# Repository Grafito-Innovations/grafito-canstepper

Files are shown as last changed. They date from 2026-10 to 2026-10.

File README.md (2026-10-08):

# Grafito CANStepper

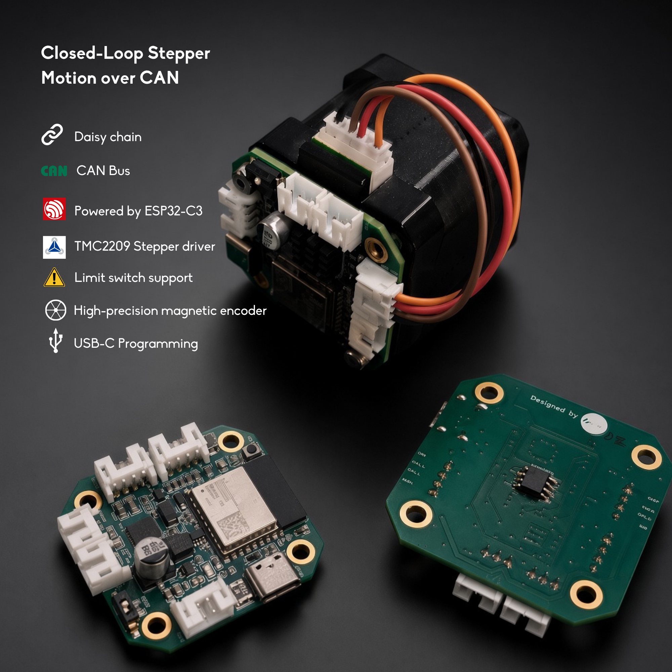
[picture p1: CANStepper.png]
Grafito CANStepper


Closed-loop stepper motor control over CAN. Each board carries an ESP32-C3,
a TMC2209 driver, an MT6701 14-bit magnetic encoder and a CAN transceiver;
up to 31 boards daisy-chain on one 1 Mbps bus and are driven from Python
through the USB port of any board on the chain.

```
├── canstepper/                              # Python package (grafito-canstepper)
├── firmware/GrafitoCANStepper_C3/           # node firmware (GCSP v1, fw 1.12)
├── firmware/GrafitoCANStepper_C3_CANopen/   # optional CiA 301/402 SKU (fw 2.1)
├── examples/                                # runnable examples + machine.toml
├── tests/                                   # pytest suite (runs on a software sim)
├── model_assets/                            # assembly render, PCB drawing, STEP CAD
└── docs/                                    # flashing, protocol, quickstart, CAD
```

## Product links

- **Shop / brochure:** [CANStepper Adapter Board](https://grafito.in/shop/products/canstepper-adapter-board/)
- **Amazon (India):** https://www.amazon.in/dp/B0H8XZ6V99
- **Docs:** https://docs.grafito.in
- **Board test station:** https://docs.grafito.in/dashboard
- **Mechanical CAD & drawings:** https://docs.grafito.in/docs/mechanical-cad
- **PyPI:** [grafito-canstepper](https://pypi.org/project/grafito-canstepper/)

CAD and brochure files in this repo (`model_assets/`):

| File | Description |
| --- | --- |
| `CANStepper.png` | Product photo (also at repo root) |
| `CANStepper_pinout.png` | Connector / pinout diagram |
| `CANStepper_multiaxis_can.png` | Multi-axis CAN bus demonstration |
| `CANStepper_V1_assembly.mp4` | V1 board assembly video (historical) |
| `CANStepper_V1_assembly_preview.jpg` | Preview frame for the V1 video |
| `CANStepper_test_station.png` | Board Test Station (after USB connect) |
| `CANStepper_block_diagram.png` | System block diagram |
| `CANStepper_V2_Assembly.webp` | V2 assembly render |
| `Drawing_CANStepper_V2.pdf` | V2 PCB mechanical drawing |
| `CANStepperV2_3D_PCB.step` | V2 PCB STEP |
| `CASING_MOUNT.step` | Casing / mount STEP |
| `Heat_Spreader.step` | Heat spreader STEP |
| `TMC2209 UART Stepper Driver - Heat_Sink.step` | TMC2209 heatsink STEP |
| `canstepper-brochure-v2.pdf` | Product brochure |

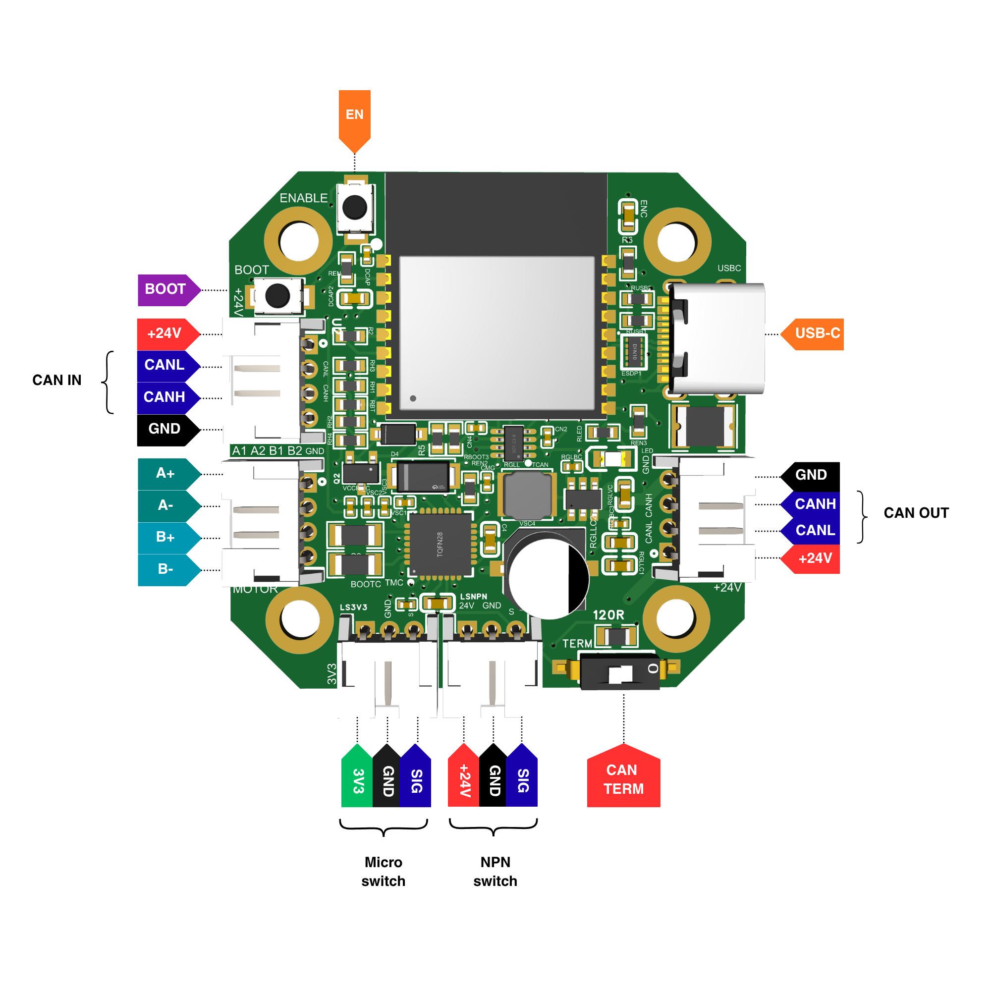
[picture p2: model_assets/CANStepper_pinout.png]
CANStepper pinout


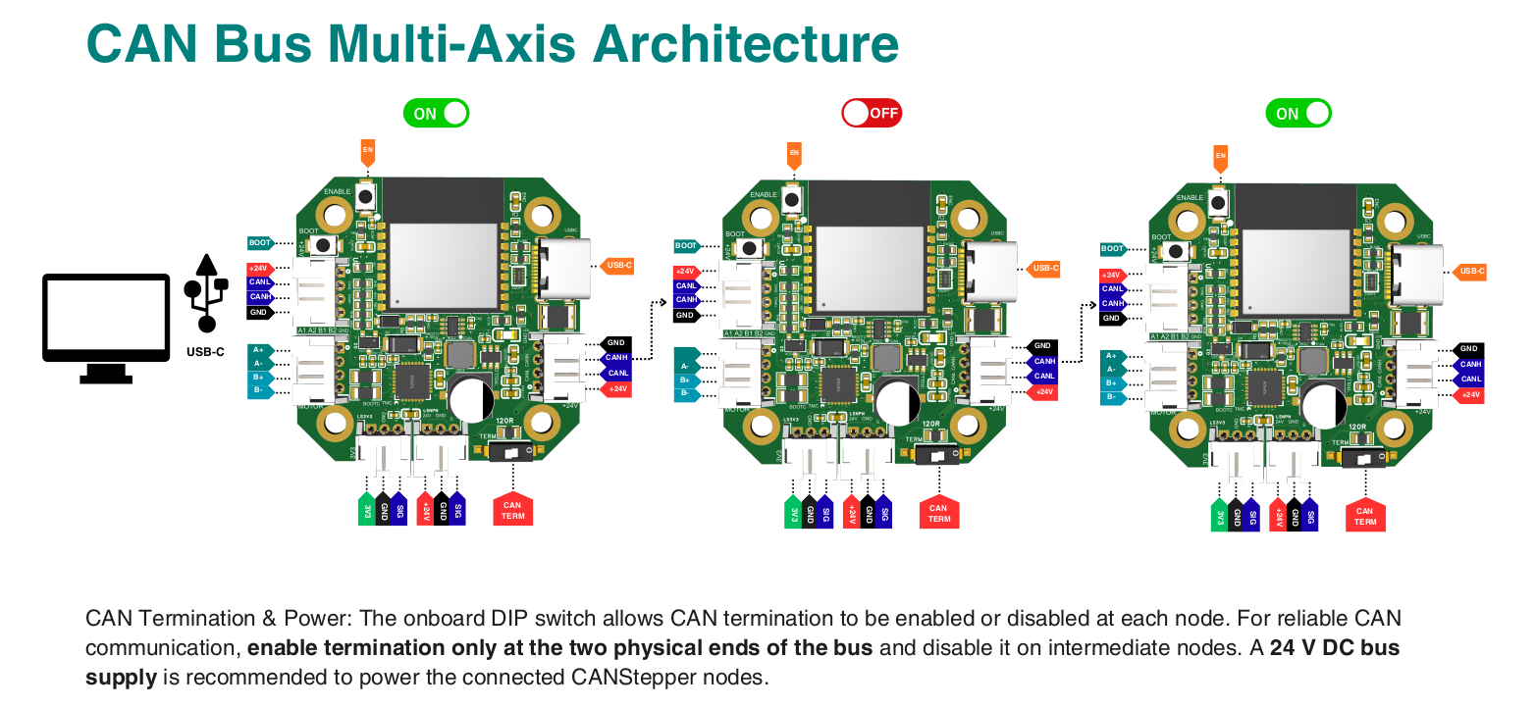
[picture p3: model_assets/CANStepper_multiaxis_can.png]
CAN bus multi-axis demonstration


**V1 board assembly** (click the preview to play the video):

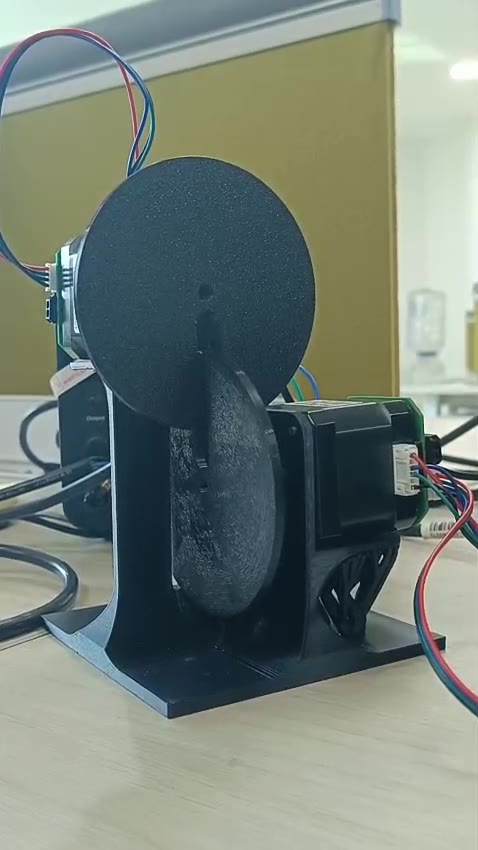
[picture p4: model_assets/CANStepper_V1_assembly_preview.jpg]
V1 board assembly


This clip is **version 1** of the same board. V1 used **three different
connector types**, which made cabling and crimping difficult. The current
production board is **V2**, with **JST 2.0** connectors throughout for easy
crimping.

> **Important — encoder magnet:** Fit a **diametrical** magnet on the motor
> shaft. The magnet polarity must be **radial**, not axial. An axial magnet
> will not produce a valid MT6701 angle and closed-loop control will fail.

After USB and Vin are connected, test the board in the
**[CANStepper Test Station](https://docs.grafito.in/dashboard)** — set the
node ID, enable the driver, jog, and check encoder / TMC / CAN telemetry.

<a href="https://docs.grafito.in/dashboard">
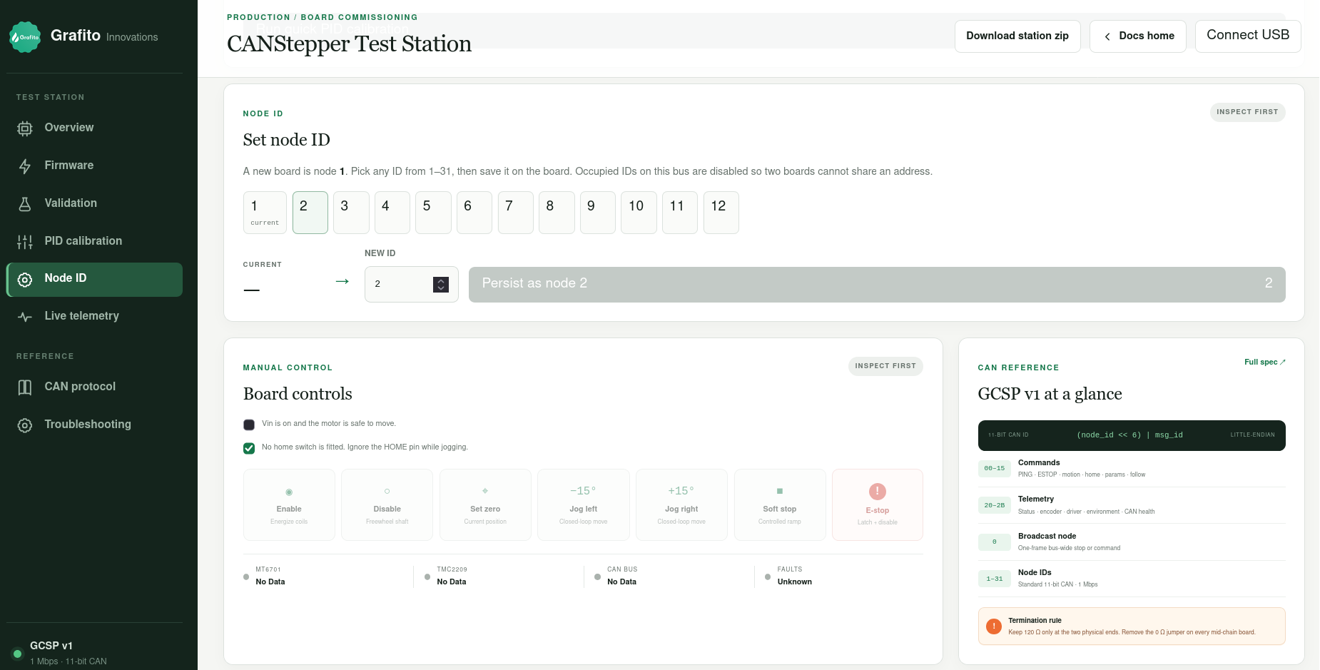
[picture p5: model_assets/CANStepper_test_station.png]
CANStepper Test Station
  
</a>

## Highlights

- **Layered Python API** — raw frames → `StepperNode` → `NodeGroup` →
  `Axis` (mm units via `rotation_distance`) → `DualMotorAxis` /
  `IndependentDualAxis` / `Cartesian` / `CoreXY` / `MotionGroup` →
  declarative `machine.toml`.
- **Safety scopes** — `node.estop()`, `group.estop()`, `bus.estop_all()`
  (single broadcast frame); e-stop is latched until re-enabled.
- **Homing** — physical endstop on IO8, sensorless (StallGuard), or
  set-zero; configurable current, backoff and timeout.
- **Closed loop** — firmware ≥1.12 plans a rest-to-rest **S-curve**
  trajectory with **velocity + acceleration feedforward** and a light
  tracking PID on the MT6701 encoder (optional encoder LUT). All motion
  limits are *configurable defaults*, never hard clamps.
- **On-bus leader/follower** — dual-motor gantries stay coupled with no
  host in the loop (`DualMotorAxis`).
- **Encoder-gated dual screws** — `IndependentDualAxis` commands both
  motors independently and **blocks the next pass until both encoders**
  are within mm tolerance of the target.
- **Simulator included** — `canstepper.sim.SimNetwork` implements the whole
  protocol in software; the test suite and the examples run without hardware.

## Install & first spin

```bash
pip install grafito-canstepper

# Development (from this directory):
# pip install -U pip setuptools && pip install -e ".[dev]"
```

```python
from canstepper import CANStepperBus

with CANStepperBus.serial("/dev/ttyACM0") as bus:
    print(bus.discover())
    node = bus.node(1)
    node.set_run_current(40).enable()
    node.move_to(360.0, blocking=True)
```

Continue with:

- [docs/flashing.md](docs/flashing.md) — Arduino IDE + arduino-cli (GCSP and CANopen)
- [docs/canopen.md](docs/canopen.md) — EDS/DCF, PLC enable, tune Kp/Ki/Kd/Ka
- [docs/quickstart.md](docs/quickstart.md) — first motion
- [docs/closed_loop_tuning.md](docs/closed_loop_tuning.md) — trapezoid + v_ff
- [docs/protocol.md](docs/protocol.md) — GCSP v1 wire protocol
- [docs/mechanical_cad.md](docs/mechanical_cad.md) — CAD, drawings, assembly video

G-code examples (from this directory):

```bash
PYTHONPATH=. python3 examples/gcode_cartesian.py /dev/ttyACM0 1 2
PYTHONPATH=. python3 examples/gcode_corexy.py /dev/ttyACM0 1 2
PYTHONPATH=. python3 examples/gcode_from_file.py examples/gcode/square.gcode
```

Homing examples (IO8 endstop, StallGuard sensorless, set-zero):

```bash
PYTHONPATH=. python3 examples/home_endstop.py /dev/ttyACM0 1 -1
PYTHONPATH=. python3 examples/home_sensorless.py /dev/ttyACM0 1 -1 60
PYTHONPATH=. python3 examples/home_set_zero.py /dev/ttyACM0 1
```

Belt axis (mm):

```bash
PYTHONPATH=. python3 examples/belt_move_mm.py /dev/ttyACM0 1 50 77.2 150
```

## Development

```bash
python3 -m pytest
```

Current GCSP firmware is **1.12** (S-curve + Ka + LUT; motors off at boot
until `enable()`). Optional **CANopen 2.1** lives in
`firmware/GrafitoCANStepper_C3_CANopen/` with `GrafitoCANStepper.eds` and
`GrafitoCANStepper_Node1.dcf` / `GrafitoCANStepper_Node2.dcf`
(FileRevision 2, identity `0x00020100`). Discard any older 2.0 EDS — it
will not import this board. Node 2 must be flashed with
`-DCO_FACTORY_NODE_ID=2`. See [docs/canopen.md](docs/canopen.md) and
**https://docs.grafito.in/docs/canopen**. PLC gains: 0x200F Kp, 0x2010 Ki,
0x2011 Kd, 0x201A Ka (REAL32). Do not mix GCSP and CANopen on one bus.

**How to flash (Arduino IDE + arduino-cli, GCSP and CANopen):**
[docs/flashing.md](docs/flashing.md) · https://docs.grafito.in/docs/flashing

Firmware builds with Arduino IDE or `arduino-cli` (ESP32C3 Dev Module, USB
CDC On Boot = Enabled; libraries: FastAccelStepper, TMC2209 janelia-arduino).
**Apply Vin (5–24 V, typically 24 V) before upload** — USB-C is data only and
does not power the ESP32 for programming. CAN termination is **on by default**
(0 Ω jumper); remove that 0 Ω on mid-chain daisy-chain nodes.

```bash
arduino-cli compile --fqbn esp32:esp32:esp32c3:CDCOnBoot=cdc \
  firmware/GrafitoCANStepper_C3
arduino-cli upload -p /dev/ttyACM0 --fqbn esp32:esp32:esp32c3:CDCOnBoot=cdc \
  firmware/GrafitoCANStepper_C3
```

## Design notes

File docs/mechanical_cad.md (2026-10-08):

# Mechanical CAD & drawings

Published with in-page previews at **https://docs.grafito.in/docs/mechanical-cad**.

Source files live in `model_assets/` at the repo root. These are the **V2**
board assets used on the shop and docs sites.

| File (repo) | Published path | Description |
| --- | --- | --- |
| `CANStepper.png` | `/model-assets/canstepper.png` | Product photo |
| `CANStepper_pinout.png` | `/model-assets/canstepper-pinout.png` | Connector / pinout diagram |
| `CANStepper_multiaxis_can.png` | `/model-assets/canstepper-multiaxis-can.png` | Multi-axis CAN bus demonstration |
| `CANStepper_V1_assembly.mp4` | — | V1 board assembly video (historical) |
| `CANStepper_block_diagram.png` | `/model-assets/canstepper-block-diagram.webp` | System block diagram |
| `CANStepper_V2_Assembly.webp` | `/model-assets/canstepper-v2-assembly.webp` | V2 assembly render |
| `Drawing_CANStepper_V2.pdf` | `/model-assets/canstepper-v2-drawing.pdf` | V2 PCB mechanical drawing |
| `CANStepperV2_3D_PCB.step` | `/model-assets/canstepper-v2-3d-pcb.step` | V2 PCB STEP (~24 MB) |
| `CASING_MOUNT.step` | `/model-assets/canstepper-casing-mount.step` | Casing / mount STEP |
| `Heat_Spreader.step` | `/model-assets/canstepper-heat-spreader.step` | Heat spreader STEP |
| `TMC2209 UART Stepper Driver - Heat_Sink.step` | `/model-assets/tmc2209-heat-sink.step` | TMC2209 heatsink STEP |
| `canstepper-brochure-v2.pdf` | `/brochures/canstepper-brochure-v2.pdf` | Product brochure |

Shop product page CAD section:
https://grafito.in/shop/products/canstepper-adapter-board/#mechanical-cad

Brochure:
https://grafito.in/brochures/canstepper-brochure-v2.pdf

## Videos

| Topic | URL | Docs embed |
| --- | --- | --- |
| V1 assembly (this repo) | [model_assets/CANStepper_V1_assembly.mp4](../model_assets/CANStepper_V1_assembly.mp4) | Historical V1 board — mixed connectors |
| Assembly walkthrough | https://www.youtube.com/watch?v=ULpthBzb50s | https://docs.grafito.in/docs/mechanical-cad#assembly-video |
| Leader / follower (encoder mirror) | https://www.youtube.com/shorts/0dZ-bfxO9gM | https://docs.grafito.in/docs/motion#dual-motor-axes-eg-dual-z-gantries |

The V1 clip shows an earlier revision of the same board. V1 used **three
different connector types**, which made cabling and crimping difficult. The
current production board is **V2**, with **JST 2.0** connectors throughout.

> **Important — encoder magnet:** Use a **diametrical** magnet on the motor
> shaft. Polarity must be **radial**, not axial. An axial magnet will not
> give a valid MT6701 reading.

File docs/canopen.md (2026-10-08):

# CANopen / CiA 402 (PLC)

Optional firmware **2.1** for a PLC that imports an EDS. Production Python
machines still use **GCSP 1.12**. **Do not mix GCSP and CANopen on the same
CAN bus.**

- Firmware + EDS/DCF: `firmware/GrafitoCANStepper_C3_CANopen/`
- Flash (including factory node 2): [flashing.md](flashing.md)
- Human docs: https://docs.grafito.in/docs/canopen

Import **firmware 2.1** `GrafitoCANStepper.eds` (FileRevision 2, identity
`0x00020100`). Delete any older 2.0 EDS. For node 2 import
`GrafitoCANStepper_Node2.dcf` and flash with `-DCO_FACTORY_NODE_ID=2`.

Enable: controlword `0x6040` = `6 → 7 → 15`. Units are encoder counts
(16384 / rev).

## Tune gains from the PLC

Closed-loop command is:

```
v = v_ff + Ka · a_ff + PID(r − encoder)
```

PID only **trims lag**. Cruise speed is **not** a PID gain — set that with
`0x6081`. Write the gain objects as **REAL32** (IEEE-754). In TwinCAT /
Codesys map them as **REAL**. Do not write integer `10` into `0x200F`; it
must be float `10.0`.

### Objects to change

| Index | Name | Type | Factory | What it does |
| --- | --- | --- | --- | --- |
| **0x200F** | Kp | REAL32 | **10.0** | Stiffness. Raise if it lags the plan; lower if it buzzes. |
| **0x2011** | Kd | REAL32 | **0.35** | Damping. Raise if it rings at the end of a move. |
| **0x2010** | Ki | REAL32 | **0.3** | Steady-state. Keep small; too much causes overshoot / following error `0x7122`. |
| **0x201A** | Ka | REAL32 | **0.04** | Accel feedforward. Raise if it sags during accel/decel. |
| **0x2012** | PID tolerance | REAL32 | **0.35°** | Target-reached band. Too tight at high RPM → `0x7122`. |

### Set these before touching PID

| Index | Name | Notes |
| --- | --- | --- |
| **0x2006** | Invert | `1` if a positive target runs the wrong way (PID will fight the encoder). |
| **0x2003** | Run current % | Start **30–40**. Gains cannot fix a starved motor. |
| **0x2007** | Closed loop | Must be **1** for encoder PID (`0` = open-loop step pulses). |
| **0x6081** | Profile velocity | counts/s. Default `32768` ≈ 720 °/s. |
| **0x6083** | Profile accel | counts/s². Default `65536` ≈ 1440 °/s². |
| **0x201B** | Jerk | deg/s³. **0 = auto** (amax / 0.05 s). |

Save so it survives power-cycle: write **0x2008 = 1**.

### Order on the PLC

1. Enable `6 → 7 → 15`, confirm `0x2007 = 1`, invert with `0x2006` if needed.
2. Set a modest `0x6081` / `0x6083` and current **30–40**.
3. Leave **Ki = 0.3** and **Ka = 0.04**.
4. Change **Kp** in steps of ~2 (try 8 → 10 → 12).
5. If it oscillates at settle, raise **Kd** (0.35 → 0.5) or drop Kp.
6. Only then nudge **Ka** or **Ki**.
7. Write `0x2008 = 1` when it is good.

Measured precision defaults (fw 2.1 / GCSP 1.12): Kp **10**, Ki **0.3**,
Kd **0.35**, Ka **0.04**, tolerance **0.35°**.

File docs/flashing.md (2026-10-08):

# Flashing firmware

Step-by-step upload for a Grafito CANStepper board (ESP32-C3). Pick **one**
sketch per board. **Do not mix GCSP and CANopen on the same CAN bus** — the
ID maps collide.

| Sketch | Version | When to use |
| --- | --- | --- |
| `firmware/GrafitoCANStepper_C3` | **GCSP 1.12** | Python (`grafito-canstepper`), G-code, Test Station |
| `firmware/GrafitoCANStepper_C3_CANopen` | **CANopen 2.1** | PLC that imports an EDS / DCF |
| `firmware/CANStepper_WiFiPortal` | demo | Phone browser bench UI only |

Public docs: **https://docs.grafito.in/docs/flashing**  
Firmware downloads: **https://docs.grafito.in/docs/firmware**  
Source: **https://github.com/Grafito-Innovations/grafito-canstepper**

## 1. Power and USB (do this first)

USB-C on this board is **data only**. It does **not** power the ESP32 for
programming.

1. Apply **Vin 5–24 V** (typically **24 V**) to the power / CAN connector.
2. Then plug USB-C into the host.
3. Keep Vin connected for the whole compile + upload. If Vin drops, the port
   disappears and the flash fails.

Do **not** hold a HOME switch closed at power-on. GPIO8 is a strapping pin:
if it is held LOW at reset, the C3 can enter download boot and look “dead”.
Leave HOME open (pin HIGH) until the board has booted.

## 2. Host tools (once per computer)

### Option A — Arduino IDE 2 (GUI)

1. Install [Arduino IDE 2](https://www.arduino.cc/en/software).
2. **File → Preferences → Additional boards manager URLs**, add:

   ```
   https://espressif.github.io/arduino-esp32/package_esp32_index.json
   ```

3. **Boards Manager:** install **esp32** by Espressif Systems.
4. **Library Manager:** install
   - **FastAccelStepper** (gin66)
   - **TMC2209** (janelia-arduino / Peter Polidoro)

### Option B — arduino-cli

```bash
curl -fsSL https://raw.githubusercontent.com/arduino/arduino-cli/master/install.sh | sh
export PATH="$HOME/bin:$PATH"

arduino-cli config init
arduino-cli config add board_manager.additional_urls \
  https://espressif.github.io/arduino-esp32/package_esp32_index.json
arduino-cli core update-index
arduino-cli core install esp32:esp32
arduino-cli lib install FastAccelStepper
arduino-cli lib install TMC2209
```

On Debian/Ubuntu, add your user to `dialout` (log out and back in once):

```bash
sudo usermod -aG dialout "$USER"
```

## 3. Board settings (both IDE and CLI)

| Setting | Value |
| --- | --- |
| Board | **ESP32C3 Dev Module** |
| USB CDC On Boot | **Enabled** |
| Upload Speed | 921600 (drop to 115200 if uploads flake) |
| Flash Size | 4 MB (default) |
| Port | Linux `/dev/ttyACM0`, macOS `/dev/cu.usbmodem*`, Windows `COMx` |

**Arduino IDE:** **Tools → Board → esp32 → ESP32C3 Dev Module**, then
**Tools → USB CDC On Boot → Enabled**, then **Tools → Port**.

**FQBN** used by `arduino-cli`:

```
esp32:esp32:esp32c3:CDCOnBoot=cdc
```

Find the port after Vin + USB are connected:

```bash
# Linux
ls /dev/ttyACM* /dev/ttyUSB*

# macOS
ls /dev/cu.usbmodem*

# Windows (PowerShell)
Get-CimInstance Win32_SerialPort | Select-Object DeviceID, Name
```

If two ACM devices appear, pick the CDC serial port (the one that shows the
boot banner at 115200). Opening that port **resets** the ESP32-C3 — wait for
the banner before talking to the board.

## 4. Flash GCSP 1.12 (Python / Test Station)

Arduino requires the folder name to match the `.ino` name. In this repo that
is already `firmware/GrafitoCANStepper_C3/GrafitoCANStepper_C3.ino`.

### Arduino IDE

1. **File → Open** `firmware/GrafitoCANStepper_C3/GrafitoCANStepper_C3.ino`.
2. Confirm board / CDC / port from the table above.
3. Click **Upload**. Wait until you see “Hard resetting via RTS pin…”.
4. **Tools → Serial Monitor**, 115200 baud.

### arduino-cli

From the repository root:

```bash
arduino-cli compile --fqbn esp32:esp32:esp32c3:CDCOnBoot=cdc \
  firmware/GrafitoCANStepper_C3
arduino-cli compile --upload -p /dev/ttyACM0 \
  --fqbn esp32:esp32:esp32c3:CDCOnBoot=cdc \
  firmware/GrafitoCANStepper_C3
```

Windows: replace `-p /dev/ttyACM0` with `-p COM5` (your port).

### Healthy GCSP banner

```
# GrafitoCANStepper fw 1.12 proto 1
# HOME pin GPIO8 INPUT_PULLUP raw=HIGH (strapping: keep HIGH at power-on)
# HOME: INPUT_PULLUP + endstop enable=1 active_high=1 action=stop (fw 1.12)
# POWER: enable_on_boot=0 hold<=5 run<=40 standstill=freewheel (fw 1.9)
# MT6701 SSI mode=3 encoder-loss-filter=25ms
# CAN started (1 Mbps)
```

Motors stay **off** until the host calls `enable()` (fw ≥1.9). Continue with
[quickstart.md](quickstart.md) or the
[Test Station](https://docs.grafito.in/dashboard).

GCSP node ID is stored in NVS and **survives a reflash**. Default is **1**.
Change it from Python (`node.set_node_id(n)` then `save_config()`), then
power-cycle. Do this **before** putting two boards on one CAN bus.

## 5. Flash CANopen 2.1 (PLC)

Flash the **folder**, not a lone `.ino`. The sketch includes `canopen_stack.h`.

```
firmware/GrafitoCANStepper_C3_CANopen/
  GrafitoCANStepper_C3_CANopen.ino
  canopen_stack.h
  GrafitoCANStepper.eds
  GrafitoCANStepper_Node1.dcf
  GrafitoCANStepper_Node2.dcf
```

Same board settings as GCSP (ESP32C3 Dev Module, USB CDC On Boot Enabled,
FastAccelStepper + TMC2209).

### Factory node 1 (default)

```bash
arduino-cli compile --upload -p /dev/ttyACM0 \
  --fqbn esp32:esp32:esp32c3:CDCOnBoot=cdc \
  firmware/GrafitoCANStepper_C3_CANopen
```

Heartbeat COB-ID is `0x701`. Import `GrafitoCANStepper.eds`, then
`GrafitoCANStepper_Node1.dcf` if the PLC wants a commissioned instance.

### Factory node 2 (customer PLC pack)

If the PLC imports **`GrafitoCANStepper_Node2.dcf`**, the board **must** be
node 2. Heartbeat `0x702`, SDO `0x602` / `0x582`, RPDO1 `0x202`, TPDO1 `0x182`.

**arduino-cli:**

```bash
arduino-cli compile --upload -p /dev/ttyACM0 \
  --fqbn esp32:esp32:esp32c3:CDCOnBoot=cdc \
  --build-property "compiler.cpp.extra_flags=-DCO_FACTORY_NODE_ID=2" \
  firmware/GrafitoCANStepper_C3_CANopen
```

**Arduino IDE:** at the **top** of `GrafitoCANStepper_C3_CANopen.ino` (before
the `#ifndef CO_FACTORY_NODE_ID` block), add:

```cpp
#define CO_FACTORY_NODE_ID 2
```

Then Upload. Revert that line before flashing a node-1 board.

### Healthy CANopen banner (node 2)

```
# GrafitoCANStepper CANopen fw 2.1 CiA402
702 0 00
# CAN started (1000000 bit/s) node 2
702 0 7F
```

Opening the USB serial monitor **resets** the C3. Wait for `7F` (pre-operational
heartbeat) before the PLC starts SDOs.

CANopen NVS namespace is `co402`. It does **not** inherit a GCSP node ID.
After a first flash, if NVS already stored a different ID, write object
`0x2000` = desired ID, `0x2008` = 1 (save), then reset.

PLC import: delete any older **2.0** EDS (revision `0x00020000`), then import
the **2.1** `GrafitoCANStepper.eds` (FileRevision 2, revision `0x00020100`)
and the matching Node DCF.

## 6. Confirm the flash

| You flashed | Serial (115200) | Host check |
| --- | --- | --- |
| GCSP 1.12 | `fw 1.12 proto 1` | `pip install -U grafito-canstepper` then `bus.discover()` → `{1: '1.12'}` |
| CANopen 2.1 node 1 | `CANopen fw 2.1` and `node 1` | Heartbeat `701 0 7F`. Python `discover()` is **empty** (wrong protocol) |
| CANopen 2.1 node 2 | `node 2` | Heartbeat `702 0 7F` |

Empty `discover()` after a CANopen flash is expected. Re-flash GCSP if you
need Python again.

## 7. If upload fails

| Symptom | Fix |
| --- | --- |
| Port missing / board not found | Vin first, then USB. Close Serial Monitor, Test Station, and other scripts. |
| `Failed to connect to ESP32: No serial data` | CDC On Boot was **Disabled** on the last flash, or GPIO8 held LOW at reset. Release HOME, hold **BOOT**, tap **RESET**, retry upload, then release BOOT. |
| Upload starts then stalls | Drop upload speed to 115200. Use a short USB data cable (not charge-only). |
| Linux `Permission denied` | `sudo usermod -aG dialout $USER` and re-login. |
| Banner is CANopen but you wanted Python | You flashed the PLC sketch. Flash `GrafitoCANStepper_C3`. |
| Two boards, CAN silent / collisions | Both still node 1. Set unique IDs **before** joining the bus. |
| PLC talks, motor never enables | Enable `6 → 7 → 15`. If HOME is already active, set `0x200C = 0`. |

## Related

- [Firmware downloads](https://docs.grafito.in/docs/firmware)
- [CANopen / CiA 402](canopen.md) — EDS, DCF, [tune gains from the PLC](canopen.md#tune-gains-from-the-plc)
- [Quickstart](quickstart.md)
- [Hardware (docs site)](https://docs.grafito.in/docs/hardware)

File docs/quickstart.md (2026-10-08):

# Quickstart — Grafito CANStepper (GCSP v1)

## 1. Hardware + firmware

Board: **[CANStepper Adapter Board](https://grafito.in/shop/products/canstepper-adapter-board/)** on the Grafito shop.
The current production board is **V2** (JST 2.0 connectors). Earlier **V1**
boards used three different connector types and are harder to cable.

> **Important — encoder magnet:** Mount a **diametrical** magnet on the shaft
> over the MT6701 (≈1–2 mm air gap). Magnet polarity must be **radial**, not
> axial. An axial magnet will not produce a valid encoder angle.

1. Apply main Vin (**5–24 V**, typically **24 V**). **USB does not power the
   ESP32 for programming** — Vin is required to flash; USB-C is data only.
2. Flash `firmware/GrafitoCANStepper_C3` (ESP32-C3, **USB CDC On Boot: Enabled**)
   with Vin connected. Full procedure: [flashing.md](flashing.md).
3. Open a serial monitor once: you should see a boot banner like  
   `# GrafitoCANStepper fw 1.12 proto 1` and an MT6701 self-check line with a
   live angle.
4. CAN: termination is **enabled by default** (0 Ω jumper → 120 Ω path). For
   daisy-chain mid-nodes, **remove the 0 Ω resistor**; keep termination on the
   two physical ends (pads can be shorted to restore end termination).
5. With USB and Vin connected, open the
   **[CANStepper Test Station](https://docs.grafito.in/dashboard)** to set the
   node ID, enable the driver, jog, and confirm encoder / TMC / CAN telemetry.

   <a href="https://docs.grafito.in/dashboard">
     CANStepper Test Station
   </a>
6. Install the host library (PyPI: `grafito-canstepper`, import `canstepper`):

```bash
pip install grafito-canstepper

# Development (editable, from this directory):
# pip install -U pip setuptools && pip install -e ".[dev]"
```

## 2. Talk to a node

```python
from canstepper import CANStepperBus

bus = CANStepperBus.serial("/dev/ttyACM0")
print(bus.discover())                        # {1: '1.12'}
node = bus.node(1)
node.enable()
print(node.get_position())                   # encoder degrees
```

## 3. Open-loop spin

```python
node.set_closed_loop(False)
node.set_run_current(40).set_microsteps(16)
node.run(360.0)          # deg/s continuous
# …
node.stop()
```

Open-loop **position** moves use FastAccelStepper’s own trapezoid
(accel → cruise → decel).

## 4. Direction polarity (important for closed loop)

Positive commands must make the encoder angle **increase**. If closed loop
runs away or faults with `NO_PROGRESS`, invert once and persist:

```python
node.set_direction(inverted=True)
node.save_config()
```

## 5. Closed-loop position moves (firmware ≥1.2)

Firmware **1.2+** plans a rest-to-rest **trapezoidal trajectory** for every
`MOVE_ABS` / `MOVE_REL` in closed loop:

```
v_ff(t)  = trapezoid(vmax=cl_max_speed, amax=cl_max_accel)
r(t)     = ∫ v_ff
v_cmd    = v_ff + Kp·(r − encoder) + Ki·∫ − Kd·v_meas
```

Same style of trap generator as [Klipper kinematics](https://www.klipper3d.org/Kinematics.html),
plus encoder tracking so the shaft lands on target. **Not S-curve** (no jerk
limit yet). Full theory, parameter matrix, and production numbers:
**[docs/closed_loop_tuning.md](closed_loop_tuning.md)**.

### Recommended production tune

Characterized on **PR42HS40-1204AF-02** (NEMA 17, 1.8°, 1.2 A, 3.2 mH,
4.2 kg·cm, D-shaft) at **24 V**, firmware **1.2**. Full matrix + **10 min
soak (478/478 settles, 100% success)** in
**[docs/closed_loop_tuning.md](closed_loop_tuning.md)**.

| Setting | Value | Why |
|---|---|-----|
| `cl_max_speed` | **4800 deg/s** (800 RPM) | Production cruise; soak-proven |
| Max proven | 6000 deg/s (1000 RPM) | OK at 70% (and short 100% bursts) |
| OL ceiling | ~7200 deg/s (1200 RPM) | Continuous `run()` tracking |
| `run_current` | **70%** | Continuous duty; 100% OK for short bursts only |
| `microsteps` | **8** | Best consistency vs 4 / 16 |
| `stealthchop` | **False** (SpreadCycle) | StealthChop sags at speed |
| Tracking PID | kp=12, ki=0.3, kd=0.10, tol=0.35° | Trim around v_ff only |

```python
node.configure_closed_loop_speed(
    4800.0,                 # cruise deg/s (÷6 = RPM)
    run_current=70,
    microsteps=8,
    stealthchop=False,      # SpreadCycle — required at high speed
    persist=True,
)
node.enable()
node.set_zero()
node.move_to(720.0, blocking=True)
```

### Quick matrix highlights (PR42HS40-1204AF-02, fw 1.12, 8 µstep, SpreadCycle)

| Current | Settles 720…6000? | Notes |
|---|---|---|
| 40–85% | Yes | Prefer **70%** continuous |
| 100% (with cool-down) | Yes in dedicated retest | USB drop risk if hammered hard |
| Open-loop `run()` @ 70–100% | Tracks to **~7200** deg/s | Continuous spin, no settle |
| Closed-loop position @ 70% | Cruise **4800–6000** | 10 min soak: **100% success** |

### Why closed-loop can look slower than open-loop `run()`

| Mode | Profile | Settles? |
|---|---|---|
| Open-loop `run()` | Constant speed | No |
| Open-loop `move_to` | Trapezoid (FAS) | Step count only |
| CL pre-1.1 | Pure PID chase | Overshoots at high vmax |
| CL 1.1 | Braking-capped PID | No planned cruise |
| CL 1.2 | Trap + v_ff + PID | Planned cruise + stop |
| **CL ≥1.12** | **S-curve + Ka + PID** | **Planned cruise + stop** |

Open-loop velocity never decelerates to a target. Closed-loop must. On long
moves, 1.12 reaches cruise if the distance is long enough — expected.

### Measure your motor

```bash
python3 tools/cl_speed_validate.py /dev/ttyACM0 1 70 8
python3 tools/cl_matrix.py /dev/ttyACM0 1 --quick
python3 examples/closed_loop_speed.py /dev/ttyACM0 1 4800
python3 examples/high_speed_test.py /dev/ttyACM0 1 70
```

## 6. Axis units (mm)

```python
from canstepper import Axis

axis = Axis(node, rotation_distance=8.0, name="z")  # 8 mm / rev leadscrew
axis.move_to(50.0, blocking=True)                   # mm
```

## 7. Homing

```python
# Endstop on IO8 (must be HIGH at boot — strapping pin):
node.configure_endstop(enabled=True, active_high=False, action="stop")
axis.home(method="endstop", direction=-1, speed=8.0, backoff=1.0)

# No switch? Sensorless (StallGuard) against a hard stop:
node.set_stall_threshold(60)
axis.home(method="stallguard", direction=-1, speed=5.0, current_percent=25)
```

## 8. Multi-axis time-sync

Host-side `MotionGroup` also uses trapezoid duration math so several axes
finish together (point-to-point, not continuous contouring / look-ahead):

```python
from canstepper import MotionGroup

g = MotionGroup([axis_x, axis_y])
g.move_to({"x": 10.0, "y": 20.0}, blocking=True)
```

## 9. Emergency stop

```python
node.estop()                 # one node (latched; enable() to recover)
bus.group([2, 3]).estop()    # a set of nodes
bus.estop_all()              # every node, single broadcast frame
```

## 10. Whole machines from a config file

See `examples/machine.toml`, then:

```python
from canstepper import Machine

with Machine.from_config("machine.toml") as m:
    m.home("z")
    m.axes["z"].move_to(50.0, blocking=True)
```

## Troubleshooting

| Symptom | Check |
|---|---|
| Flash fails / no CDC | **Vin (5–24 V) applied?** USB does not power ESP32 for programming |
| `discover()` is empty | Vin + USB; port name; USB CDC On Boot; `#` boot lines visible? |
| Motor silent, no hold | `node.enable()`; `run_current`; Vin present (typically 24 V) |
| Stalls / won't settle in closed loop | Raise `cl_max_speed`/`cl_max_accel`; SpreadCycle + higher current; fewer µsteps; `configure_closed_loop_speed()` |
| Closed loop slower than open-loop `run()` | Expected for short moves (accel+decel+settle); on long moves use fw ≥1.2 and raise cruise to the OL ceiling |
| Angle noisy / jumps while stationary | MT6701 SSI `SPI_MODE3`; magnet centering/gap; CLK/DO/CS wiring |
| Closed loop runs away / `NO_PROGRESS` | Toggle `node.set_direction(True)` so +command increases encoder |
| Encoder fault code 1 | Sustained SSI loss; reflash latest firmware (rides through isolated CRC errors) |
| Two-node bus dead | Default term ON — ends keep 0 Ω / pads shorted; mid-chain **remove 0 Ω**; `get_can_health()` |
| Board won't boot with endstop wired | IO8 HIGH at reset (strapping pin) |

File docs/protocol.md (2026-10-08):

# Grafito CAN Stepper Protocol v1 (GCSP v1)

Wire protocol between a host and Grafito CANStepper boards. This document is
sufficient to implement an independent host client. The Python reference
implementation is `canstepper/protocol.py`; the firmware is
`firmware/GrafitoCANStepper_C3/`.

## Physical layer

- CAN 2.0A, **standard 11-bit identifiers**, **1 Mbps**, TCAN3413 transceiver.
- Daisy-chained nodes; up to **31 nodes** per bus.
- On-board **120 Ω termination is enabled by default** via a **0 Ω jumper**.
  Keep termination only on the **two physical ends** of the bus; **remove the
  0 Ω resistor** on intermediate (mid-chain) boards. End boards can short the
  termination pads if the jumper was removed and end termination is needed again.

## Addressing

```
CAN ID (11 bit) = (node_id << 6) | msg_id
```

| Field | Bits | Range | Meaning |
|---|---|---|---|
| `node_id` | 10..6 | 0–31 | 0 = broadcast (every node executes), 1–31 = one board |
| `msg_id` | 5..0 | 0–63 | 0–31 command (host→node), 32–63 telemetry (node→host) |

- All multi-byte payload values are **little-endian**.
- A **remote frame (RTR)** carrying a telemetry `msg_id` requests that node to
  transmit the telemetry immediately (poll). Data frames with telemetry IDs
  are never executed as commands.
- Nodes also broadcast telemetry periodically: the *fast* group
  (POSITION, MOTION, PID_STATUS) at `fast_rate_hz` (default 10 Hz) and the
  *slow* group (STATUS, DRIVER, ENV, FOLLOW_STATUS, CAN_HEALTH) at
  `slow_rate_hz` (default 1 Hz). Either rate can be 0 (off).

## Serial bridge

Any node bridges its USB CDC port (115200 baud) to the bus. One text line per
frame, in both directions:

```
<CAN_ID hex> <RTR 0|1> <payload hex>\n
```

Example — command node 1 to 180°: `44 0 0000000000C06640`
(`0x44 = (1<<6)|4`, MOVE_ABS, f64 little-endian 180.0).

- Payload length = hex-digit count / 2 (0–8 bytes). RTR lines carry no payload.
- Lines beginning with `#` are human-readable debug output — ignore them.
- The bridging node executes bridged frames addressed to it (or broadcast)
  *and* re-transmits them on CAN; every frame it sees on the bus, plus its own
  telemetry, is printed to the port.

## Commands (msg_id 0–31)

| # | Name | Payload | Behavior |
|---|---|---|---|
| 0 | `PING` | — | Node answers with STATUS immediately. |
| 1 | `ESTOP` | — | Instant stop + driver hardware-disable. **Latched**: motion commands are ignored until `ENABLE 1`. |
| 2 | `STOP` | — | Decelerating stop; driver stays energized; cancels homing/velocity/position. |
| 3 | `ENABLE` | `u8` 0/1 | Driver off/on. Enabling clears the e-stop latch. Disabling force-stops. |
| 4 | `MOVE_ABS` | `f64` deg | Absolute position move. Open-loop: FAS trapezoid to step target. Closed-loop (fw ≥1.11): rest-to-rest S-curve + velocity/accel FF + tracking PID to encoder. |
| 5 | `MOVE_REL` | `f64` deg | Relative to the active target (or current position if idle). Same open/closed profiles as `MOVE_ABS`. |
| 6 | `MOVE_VEL` | `f32` deg/s | Signed continuous velocity; 0 = ramped stop. |
| 7 | `SET_ZERO` | — | Stop; current shaft angle becomes 0°. |
| 8 | `HOME` | `u8` method, `i8` dir, `f32` speed deg/s | Homing routine, see below. |
| 9 | `SET_PARAM` | `u8` id, 4-byte value | Set a parameter; node replies with PARAM (status + readback). |
| 10 | `GET_PARAM` | `u8` id | Node replies with PARAM. |
| 11 | `SAVE_CONFIG` | — | Persist all parameters to flash (applied at every boot). |
| 12 | `LOAD_DEFAULTS` | — | Factory defaults + persist; the node **keeps its ID**. |
| 13 | `FOLLOW` | `u8` en, `u8` leader, `u8` flags, `u8` rsvd, `f32` ratio | flags bit0 = invert, bit1 = encoder-corrected. |
| 14 | `FOLLOW_SYNC` | — | Recapture leader/local zero offset on the next leader frame. |
| 15 | `SET_POSITION` | `f64` deg | Stop and label the current physical shaft position with this logical angle; no motion. |
| 16 | `LUT` | `u8` action | Encoder LUT (fw ≥1.10): 0 = 200-step bidir calibration, 1 = enable, 2 = disable, 3 = clear. Calibration emits `LUT_DONE` / `LUT_FAILED`. |
| 17–31 | reserved | | Ignored. |

### Homing (`HOME`)

`method`: 0 = **set-zero** (define zero here), 1 = **endstop** (IO8),
2 = **StallGuard** (sensorless). `dir`: +1 / −1. Sequence for methods 1–2:

1. Optionally switch to `homing_current` (param 25; 0 = keep run current).
2. Run at the commanded speed and direction until the trigger
   (endstop active / TMC DIAG rising edge) or `homing_timeout_ms`.
3. Force-stop; the trigger point becomes 0°.
4. Back off `homing_backoff` degrees in the opposite direction.
5. Restore current; emit `HOMING_DONE` (or `HOMING_FAILED` on timeout) and
   set the `homed` status flag.

### Endstop (IO8)

Independent of homing, when `endstop_enable` = 1 every edge produces an
`ENDSTOP_HIT` / `ENDSTOP_RELEASED` event, and `endstop_action` selects what a
hit does to running motion: 0 report-only, 1 stop, 2 stop + zero. Polarity via
`endstop_active_high` (default active-low with internal pull-up).

> **Boot caution:** IO8 is an ESP32-C3 strapping pin. It must be HIGH at
> power-on or the chip may not boot — use normally-open switches to GND, or
> wire NC switches through a series diode.

## Parameters

4-byte values, type `u32` or `f32`. Ranges are hardware-sanity checks
(mirrored by host and firmware); **motion limits are configurable defaults,
never firmware clamps**. Persisted only on `SAVE_CONFIG`; loaded at power-on.

| ID | Name | Type | Default | Range | Description |
|----|---|---|---|---|---|
| 1 | `node_id` | u32 | 1 | 1–31 | CAN address (save + reboot recommended after change) |
| 2 | `steps_per_rev` | u32 | 200 | 1–100000 | Full steps per motor revolution |
| 3 | `microsteps` | u32 | 16 | 1–256, power of 2 | TMC2209 microstepping |
| 4 | `run_current` | u32 | 30 | 1–100 | Run current, % of driver max |
| 5 | `hold_current` | u32 | 15 | 0–100 | Standstill current, % |
| 6 | `stall_threshold` | u32 | 10 | 0–255 | StallGuard SGTHRS (higher = more sensitive) |
| 7 | `invert_dir` | u32 | 0 | 0/1 | Invert physical rotation (logical frame preserved) |
| 8 | `closed_loop` | u32 | 1 | 0/1 | MT6701 position loop for MOVE_ABS/REL |
| 9 | `max_speed` | f32 | 720 | >0 | Cruise speed for open-loop position / host planning, deg/s |
| 10 | `acceleration` | f32 | 1440 | >0 | Open-loop position ramp, deg/s² |
| 11 | `cl_max_speed` | f32 | 720 | >0 | Closed-loop **S-curve cruise** vmax, deg/s (fw ≥1.11) |
| 12 | `cl_max_accel` | f32 | 1440 | >0 | Closed-loop **S-curve peak accel** amax, deg/s² |
| 13 | `pid_kp` | f32 | 10.0 | ≥0 | Tracking Kp on (r − encoder); v_ff + Ka·a_ff carry the move |
| 14 | `pid_ki` | f32 | 0.3 | ≥0 | Tracking Ki |
| 15 | `pid_kd` | f32 | 0.35 | ≥0 | D-on-measured-velocity damping |
| 16 | `pid_tolerance` | f32 | 0.35 | 0.001–360 | Settle window, deg |
| 17 | `fast_rate_hz` | u32 | 10 | 0–500 | POSITION/MOTION/PID_STATUS rate |
| 18 | `slow_rate_hz` | u32 | 1 | 0–500 | STATUS/DRIVER/ENV/… rate |
| 19 | `enable_on_boot` | u32 | 1 | 0/1 | |
| 20 | `zero_on_boot` | u32 | 0 | 0/1 | |
| 21 | `standstill_mode` | u32 | 0 | 0–3 | 0 normal, 1 freewheel, 2 brake, 3 strong brake |
| 22 | `endstop_enable` | u32 | 0 | 0/1 | |
| 23 | `endstop_active_high` | u32 | 0 | 0/1 | |
| 24 | `endstop_action` | u32 | 1 | 0–2 | 0 report, 1 stop, 2 stop+zero |
| 25 | `homing_current` | u32 | 0 | 0–100 | 0 = keep run current |
| 26 | `homing_backoff` | f32 | 2.0 | ≥0 | deg |
| 27 | `homing_timeout_ms` | u32 | 30000 | 100–600000 | |
| 28 | `stealthchop` | u32 | 1 | 0/1 | Quiet mode (off = SpreadCycle) |
| 29 | `lut_enable` | u32 | 0 | 0/1 | Apply 200-step MT6701 LUT (fw ≥1.10; rejected if no table) |
| 30 | `cl_max_jerk` | f32 | 0 | ≥0 | S-curve jerk limit, deg/s³ (fw ≥1.11). 0 = auto (`amax/0.05`) |
| 31 | `pid_ka` | f32 | 0.04 | 0–1 | Acceleration feedforward, seconds: `v += Ka·a_ff` (fw ≥1.11; 0.04 from bench) |

## Telemetry (msg_id 32–63)

| # | Name | Payload | When |
|---|---|---|---|
| 32 | `STATUS` | `u8` flags, `u8` mode, `u8` fault, `u8` fw_major, `u8` fw_minor, `u8` proto, `u8` node_id | slow rate, PING, RTR |
| 33 | `POSITION` | `f64` encoder angle deg (multi-turn) | fast rate, RTR — **drives followers** |
| 34 | `MOTION` | `f32` measured velocity deg/s, `f32` position error deg | fast rate, RTR |
| 35 | `TARGET` | `f64` active target deg | RTR |
| 36 | `EVENT` | `u8` event, `u8` detail, `f32` data | on occurrence |
| 37 | `DRIVER` | TMC diagnostics, **8 bytes** (fw ≥1.4; see below) | slow rate, RTR |
| 38 | `ENV` | `f32` MCU temp °C, `f32` bus volts | slow rate, RTR |
| 39 | `PARAM` | `u8` param id, `u8` status (0 ok, 1 unknown, 2 rejected), 4-byte value | reply to SET/GET_PARAM |
| 40 | `FOLLOW_STATUS` | `u8` en, `u8` leader, `u8` flags, `u8` synced, `f32` ratio | slow rate (when following), RTR |
| 41 | `CAN_HEALTH` | `u8` TWAI state, `u8` tx_err, `u8` rx_err, `u8` recoveries, `u16` tx_failed, `u16` bus_errors | slow rate, RTR |
| 42 | `ENC_COUNTS` | `i64` multi-turn counts (16384/rev) | RTR |
| 43 | `PID_STATUS` | `u8` state (0 idle, 1 running, 2 settled, 3 fault), `u8` fault, `f32` output deg/s | fast rate (closed loop), RTR |
| 44 | `LUT_STATUS` | `u8` valid, `u8` enabled, `u16` n, `f32` peak INL deg | RTR (fw ≥1.10) |
| 45–63 | reserved | | |

### STATUS flag bits (byte 0)

| Bit | Meaning |
|-----|---|
| 0x01 | driver enabled |
| 0x02 | moving |
| 0x04 | homed |
| 0x08 | e-stop latched |
| 0x10 | endstop active |
| 0x20 | stall latched |
| 0x40 | encoder frame OK |

### Modes / faults / events

- **mode**: 0 idle, 1 position, 2 velocity, 3 homing, 4 following,
  5 encoder LUT calibration.
- **fault**: 0 none, 1 encoder invalid, 2 no progress (mechanical stall in
  closed loop), 3 homing timeout, 4 TMC over-temperature shutdown (OT),
  5 TMC short (S2G / low-side).
- **event**: 1 boot, 2 endstop hit, 3 endstop released, 4 stall, 5 homing
  done, 6 homing failed, 7 move done, 8 e-stop, 9 fault, 10 LUT done
  (`data` = peak INL deg), 11 LUT failed (`detail`: 1 not ready/estop,
  2 encoder, 3 table invalid, 4 busy). `data` is usually the position
  (deg) at the event (OT fault may carry MCU temp °C).

### DRIVER payload (msg_id 37, firmware ≥1.4)

| Bytes | Type | Meaning |
|---|---|---|
| 0–1 | u16 | StallGuard result |
| 2 | u8 flags_a | bit0 UART ok, bit1 **OTPW**, bit2 **OT**, bit3 S2GA, bit4 S2GB, bit5 S2VSA, bit6 S2VSB, bit7 OLA |
| 3 | u8 flags_b | bit0 OLB, bit1 t120, bit2 t143, bit3 t150, bit4 t157, bit5 stealth, bit6 standstill |
| 4 | u8 gstat | bit0 reset, bit1 drv_err, bit2 uv_cp |
| 5 | u8 | `cs_actual` (0–31) TMC current scale from `DRV_STATUS` |
| 6–7 | u16 | interstep duration (TSTEP-style, low 16 bits) |

Host conversion (library ≥0.2.1, TMC2209 datasheet, 100 mΩ sense):  
`I_RMS = (CS+1)/32 × 0.325 / ((0.100+0.020)×√2)` → `DriverStatus.commanded_rms_amps()`.  
Regulation scale only — not 24 V bus current.

Python: `node.get_driver_status()` → `DriverStatus` (includes `otpw`, `over_temp_shutdown`, …).  
OT shutdown stops motion and latches `fault=4` until `enable()`; OTPW is warning-only (flag + serial log).

### Firmware implementation (GrafitoCANStepper_C3, fw ≥1.4)

- `tmcPollStatus()` — read `getStatus()` / `getGlobalStatus()`, set OTPW/OT/short bits  
- `sendDriver()` — 8-byte `TEL_DRIVER` payload  
- `tmcDriverService()` — ~100 ms poll; OT → `FAULT_DRIVER_OT`, shorts → `FAULT_DRIVER_SHORT`  
- `setDriverEnabled(true)` — `clearDriveError()` / `clearReset()`, clear OT/short latches  

Public download + full-source preview (no private monorepo required):  
https://docs.grafito.in/docs/firmware  
and raw file https://docs.grafito.in/firmware/GrafitoCANStepper_C3.ino

## Closed-loop motion profile (firmware ≥1.11)

When `closed_loop = 1` and the node receives `MOVE_ABS` / `MOVE_REL`:

1. **Plan** a rest-to-rest 7-segment S-curve from the current encoder angle
   to the target, using `vmax = min(max_speed, cl_max_speed)`,
   `amax = cl_max_accel`, and `jerk = cl_max_jerk` (0 = auto `amax/0.05 s`).
2. **Generate** each 5 ms control tick a reference `r(t)`, velocity
   feedforward `v_ff(t)`, and acceleration feedforward `a_ff(t)`.
3. **Track** with acceleration FF plus a light PID on the residual:  
   `v_cmd = v_ff + Ka·a_ff + Kp·(r − encoder) + Ki·∫ − Kd·v_meas`.
4. **Settle** when the plan is finished, `|target − encoder| ≤ pid_tolerance`,
   and measured speed is low → emit `MOVE_DONE` (`EVT` 7).

Optional 200-step MT6701 LUT (`lut_enable`, fw ≥1.10) linearizes magnetic
detent INL before the PID sees the encoder.

Open-loop position moves still use FastAccelStepper’s internal trapezoid
via step counts (no encoder in the loop). Continuous `MOVE_VEL` is open-loop
velocity with an accel ramp only.

FOLLOW mode with encoder correction uses a continuous braking-law chase
toward the live leader target (not a re-planned S-curve each frame).

Tuning guide, hardware matrix (current / microsteps / chopper mode), and
production recommendations: **[closed_loop_tuning.md](closed_loop_tuning.md)**.

## Leader / follower

`FOLLOW` makes a node track another node's `POSITION` broadcasts entirely
on-bus. The first leader frame after enable (or after `FOLLOW_SYNC`)
captures both zero references, so the follower never jumps on engage.
`follower = local_ref + (leader − leader_ref) × ratio × (invert ? −1 : 1)`.
With flags bit1 set the follower closes its own MT6701 loop on the mapped
target (recommended); otherwise it runs open-loop steps. A 0.15° hysteresis
deadband rejects stationary leader-encoder noise without adding lag.

## Bus load

A 1 Mbps standard frame with 8-byte payload is ≈111–135 bits with stuffing.
At defaults (fast 10 Hz × 3 frames + slow 1 Hz × 5 frames ≈ 35 frames/s/node),
31 nodes ≈ 1085 frames/s ≈ **15 % bus load**. Scale `fast_rate_hz` accordingly
if you raise rates or add nodes.

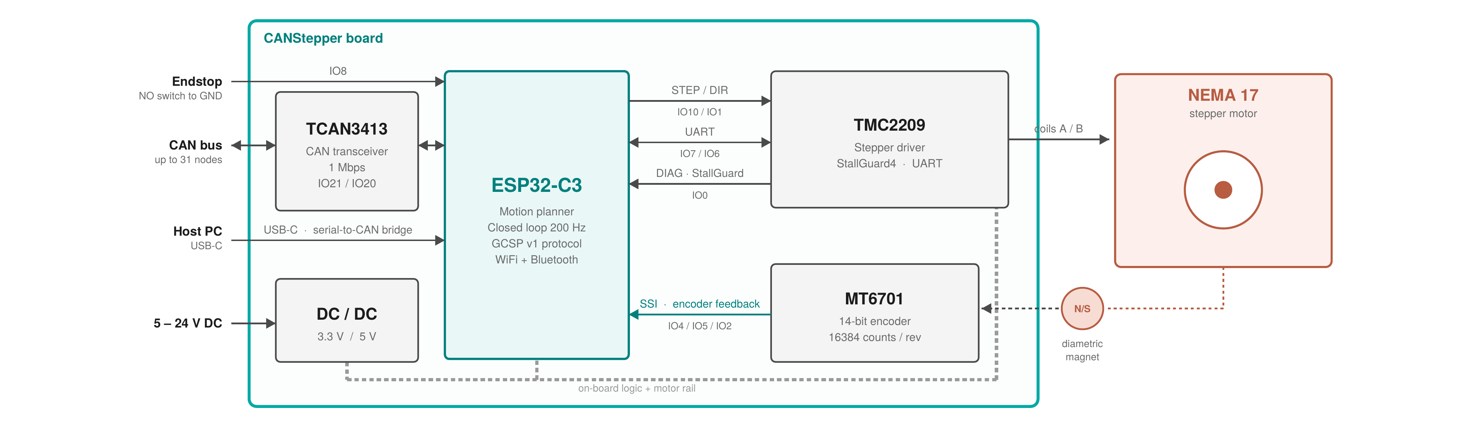
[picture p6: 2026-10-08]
model_assets/CANStepper_block_diagram.png

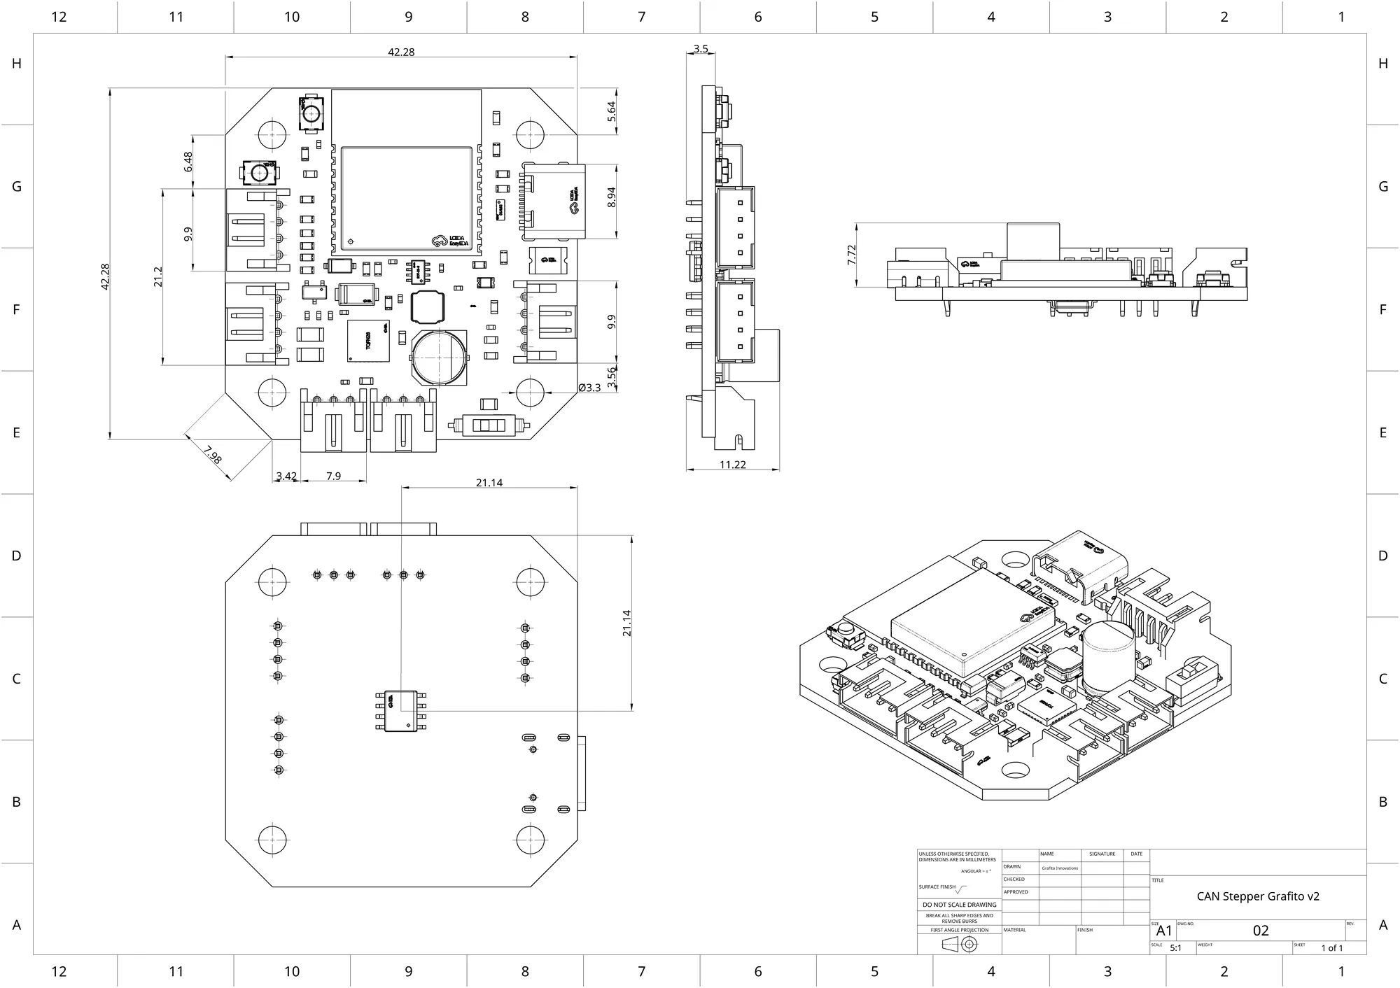
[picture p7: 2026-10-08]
model_assets/Drawing_CANStepper_V2_preview.webp

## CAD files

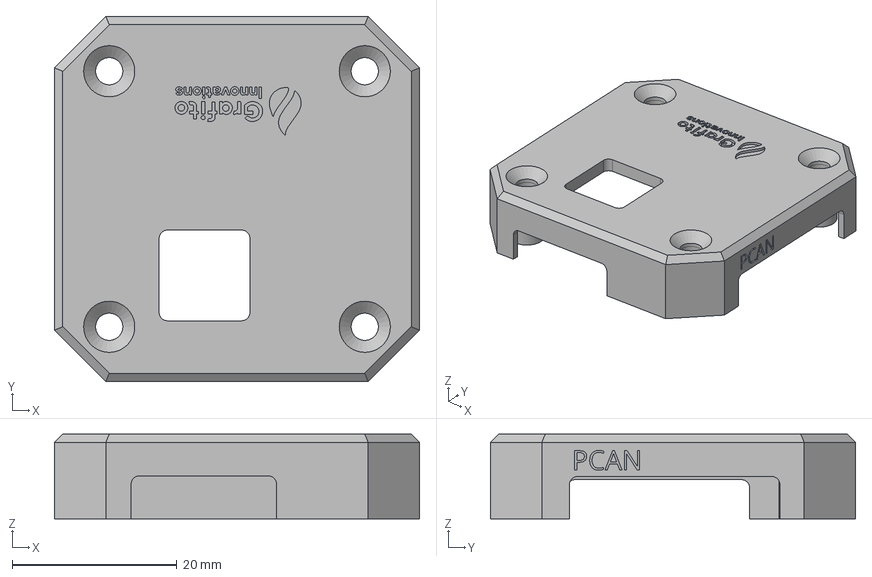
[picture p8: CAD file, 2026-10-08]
model_assets/CASING_MOUNT.step
44.3 x 44.3 x 10.3 mm

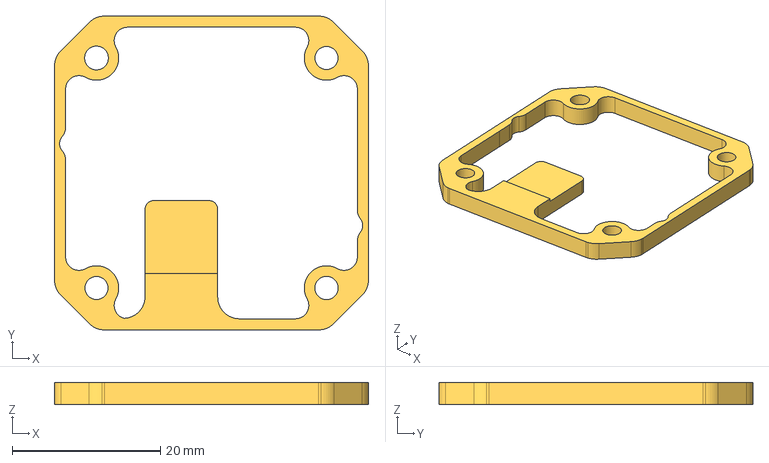
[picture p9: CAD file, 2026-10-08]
model_assets/Heat_Spreader.step
42.3 x 42.3 x 3.00 mm

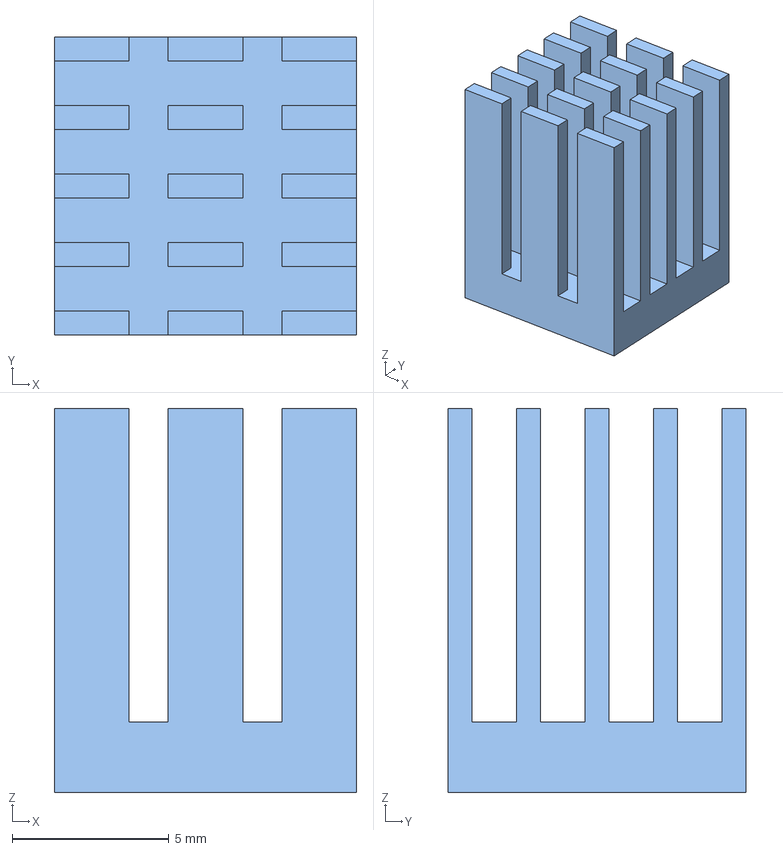
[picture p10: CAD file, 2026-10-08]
model_assets/TMC2209 UART Stepper Driver - Heat_Sink.step
9.64 x 9.50 x 12.2 mm

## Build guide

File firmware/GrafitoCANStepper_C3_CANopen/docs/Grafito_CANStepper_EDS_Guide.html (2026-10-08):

# Grafito CANStepper C3

CANopen Electronic Data Sheet (EDS) Configuration Guide

Beginner to advanced | Firmware 2.1 (CiA 301 + CiA 402 subset)
File: GrafitoCANStepper.eds | EDS version 4.0 | 13 September 2026
Grafito Innovations

This guide explains the whole EDS setup for the Grafito CAN stepper: what an EDS is, how to import it into a PLC, every object in the dictionary, and how to command motion like a drive profile. You do not need prior CANopen experience to start. Later chapters assume you have read the earlier ones.

Two firmwares, two protocols The production Python product still uses GCSP v1 (GrafitoCANStepper_C3.ino, firmware 1.12). PLC / EDS support is the separate CANopen sketch (GrafitoCANStepper_C3_CANopen, firmware 2.1 — S-curve, Ka, encoder LUT). Do not mix GCSP and CANopen nodes on the same CAN bus. Flash CANopen firmware before importing this EDS.

## Contents

1. Part 1 — Beginner: what you are configuring
2. Part 2 — Intermediate: the EDS file and object dictionary
3. Part 3 — Intermediate: CiA 402 drive profile
4. Part 4 — Advanced: PDOs, COB-IDs, SDO and bus timing
5. Part 5 — Advanced: PLC import and first-motion recipes
6. Part 6 — Reference tables and troubleshooting

## Part 1 — Beginner: what you are configuring Beginner

### 1.1 The hardware in one paragraph

A Grafito CANStepper C3 board is a small CAN node: ESP32-C3 microcontroller, TMC2209 stepper driver, MT6701 magnetic encoder (16384 counts per revolution), and a TCAN3413 CAN transceiver. Several boards can share one CAN cable. A PLC or PC talks to them by sending short CAN frames. The motor does not understand “CANopen” by itself — the firmware on the ESP32 does.

### 1.2 CAN is the wire. CANopen is the language

Think of three layers:

Layer | What it is | On this product
Physical CAN | Two wires (CAN_H / CAN_L), 11-bit IDs, up to 8 data bytes | CAN 2.0A, default 1 Mbps
CANopen (CiA 301) | Agreed meaning for those IDs: start node, read a setting, cyclic I/O | NMT, SDO, PDO, heartbeat, emergency
Drive profile (CiA 402) | Agreed meaning for a motor: enable, move, home, fault | pp / pv / hm subset

Without CANopen, a PLC only sees raw frames. With CANopen, the PLC can say “write object 0x607A (target position)” instead of packing bytes by hand.

### 1.3 What an EDS file is

An Electronic Data Sheet (CiA 306) is a text file that describes one device to a PLC configuration tool. It is not firmware and it does not move the motor. It is a catalogue:

- who made the device (vendor, product, revision)
- which bitrates it supports
- every setting and process value (the object dictionary)
- which values can ride on cyclic PDOs
- default CAN identifiers (COB-IDs)

When you import GrafitoCANStepper.eds, TwinCAT, Codesys, TIA Portal, or similar tools build a device tree from that catalogue. The PLC then uses SDO and PDO at runtime against the live node.

Three files are generated from the same object table in canopen402.py:

File | Standard | What it is
GrafitoCANStepper.eds | CiA 306 EDS | Device template. Import this to add the product to the PLC catalogue.
GrafitoCANStepper_Node1.dcf | CiA 306 DCF | One instance: node ID 1, 1 Mbps, filled COB-IDs, ParameterValue on every object. Use this when the tool asks for a DCF / “configured device”.
object_dictionary.json / .csv | Grafito export | The same object dictionary as a table. For spreadsheets, reviews, and tools that do not parse EDS.

Analogy The EDS is the datasheet. The DCF is that datasheet filled in for one board on the bus. The object dictionary is the list of registers. SDO is “read/write one register when I ask.” PDO is “keep sending these registers every cycle.” NMT is the on/off switch for the whole node.

### 1.4 Where the files live

Item | Path
EDS (device template) | can_stepper/firmware/GrafitoCANStepper_C3_CANopen/GrafitoCANStepper.eds
DCF (node 1 instance) | can_stepper/firmware/GrafitoCANStepper_C3_CANopen/GrafitoCANStepper_Node1.dcf
Object dictionary | object_dictionary.json and object_dictionary.csv (same folder)
CANopen firmware | firmware/GrafitoCANStepper_C3_CANopen/GrafitoCANStepper_C3_CANopen.ino
Protocol stack in firmware | firmware/GrafitoCANStepper_C3_CANopen/canopen_stack.h
Host / test source of truth | can_stepper/canstepper/canopen402.py
USB bring-up script | can_stepper/tools/canopen_bringup.py

### 1.5 Identity numbers the PLC will show

Field | Value | Meaning
Vendor name | Grafito Innovations | Shown in the device catalogue
Vendor number | 0x000005A3 | Development placeholder. Register a real CiA vendor ID before a production EDS
Product name | Grafito CANStepper C3
Product number | 0x00004333 | Object 0x1018:02
Revision | 0x00020100 | Firmware 2.1.0
Order code | GRAFITO-CANSTEPPER-C3
Device type 0x1000 | 0x00040192 | Stepper + CiA 402
Device name 0x1008 | CANStepper
Default node ID | 1 (range 1–127) | Not the old GCSP 1–31 limit

### 1.6 Units you must memorise

CANopen drives use integers, not floating-point degrees on the wire.

Quantity | Unit | Conversion
Position (0x6064, 0x607A) | encoder counts | 16384 counts = 360° = 1 motor revolution
Velocity (0x606C, 0x60FF, 0x6081) | counts / second | deg/s = counts/s × 360 / 16384
Acceleration (0x6083, 0x6084, 0x6085) | counts / s² | same scale. Default 65536 ≈ 1440 °/s² (0x6085 quick-stop remains 262144)

Examples: 90° = 4096 counts. 10° ≈ 455 counts. 720 °/s = 32768 counts/s (the default profile velocity).

First practical step Flash firmware 2.1, apply 24 V Vin (USB is data only), terminate the two physical ends of the CAN bus, set the PLC bitrate to 1 Mbps, import the EDS, set node ID 1, then read 0x1000 and 0x1018 before you try to move.

## Part 2 — Intermediate: the EDS file and object dictionary Intermediate

### 2.1 EDS is an INI file

Open GrafitoCANStepper.eds in any text editor. Sections look like [FileInfo], [DeviceInfo], [1000], [1018sub1]. Comments start with ;.

#### FileInfo

Metadata for the file itself: name, EDS version 4.0, author, dates. PLC tools record this; it does not change runtime behaviour.

#### DeviceInfo

Tells the tool which baud rates to offer and how many PDOs exist.

Key | This EDS | What you set on the PLC
BaudRate_125 / 250 / 500 / 1000 | 1 (supported) | Match object 0x200E. Factory default is 1 Mbps
BaudRate_10 / 20 / 50 / 800 | 0 | Do not select these
SimpleBootUpSlave | 1 | Node boots to pre-operational and waits for NMT Start
NrOfRXPDO / NrOfTXPDO | 2 / 2 | RPDO1+2, TPDO1+2
LSS_Supported | 0 | No LSS. Change node ID via 0x2000 + save + reboot
Granularity | 8 | Mapping is byte-oriented

#### Object lists

Three inventories must list every index that later appears as a section:

- MandatoryObjects — 0x1000, 0x1001, 0x1018 (CiA 301 requires these)
- OptionalObjects — communication + CiA 402 objects
- ManufacturerObjects — Grafito-specific 0x2000–0x201F

If an index is in the file but missing from these lists, many importers reject the EDS.

#### DCF extras (not in the EDS)

The DCF is the EDS plus a commissioned instance. Extra sections:

- DeviceComissioning (CiA spelling) — NodeID=1 or 2, Baudrate=1000 (kbit/s), NetworkName=GrafitoCAN
- LastEDS — points at GrafitoCANStepper.eds (firmware 2.1, FileRevision 2, identity revision 0x00020100). Delete any 2.0 EDS already in the PLC.
- ParameterValue on every object — the live instance. DefaultValue stays the factory EDS default. Node 2 COB-IDs are 0x82 / 0x602 / 0x582 / 0x202 / 0x302 / 0x182 / 0x282. Commissioned 0x200C = 0 so HOME does not kill the first jog.

Regenerate a DCF for another node with render_dcf(node_id=N). Do not hand-edit COB-IDs; they are 0x80+N, 0x180+N, 0x200+N, … Flash the matching factory node ID (-DCO_FACTORY_NODE_ID=2 for Node2.dcf).

### 2.2 Anatomy of one object

[6040]
ParameterName=Controlword
ObjectType=0x7          ; 0x7 = VAR (single value). 0x8 = ARRAY. 0x9 = RECORD
DataType=0x0006         ; UNSIGNED16
AccessType=rw           ; ro / rw / wo
DefaultValue=0
PDOMapping=1            ; 1 = may be mapped into a PDO

Records (identity, PDO communication) use [1018] plus [1018sub0] … [1018sub4]. Subindex 0 is always “number of entries.”

### 2.3 Data types used in this EDS

EDS DataType | Name | Size | Used for
0x0002 | INTEGER8 | 1 | Modes, homing method
0x0003 | INTEGER16 | 2 | Quick-stop option
0x0004 | INTEGER32 | 4 | Position, velocity (signed)
0x0005 | UNSIGNED8 | 1 | Flags, currents, node ID
0x0006 | UNSIGNED16 | 2 | Controlword, statusword, heartbeat
0x0007 | UNSIGNED32 | 4 | IDs, profile limits, mappings
0x0008 | REAL32 | 4 | PID gains, bus voltage
0x0009 | VISIBLE_STRING | variable | Name / versions (SDO segmented)

Multi-byte values are little-endian.

### 2.4 Communication objects (CiA 301)

Index | Name | Access | Role
0x1000 | Device Type | ro | Must read 0x00040192
0x1001 | Error Register | ro | Bit0 generic, bit1 current, bit3 temp, bit5 profile
0x1005 | COB-ID SYNC | rw | Default 0x080. SYNC not required for event-driven PDOs
0x1008 / 09 / 0A | Name, HW, SW version | ro | CANStepper / C3 / 2.1.0
0x1014 | COB-ID EMCY | ro | 0x080 + node ID
0x1017 | Producer heartbeat time | rw | Milliseconds. Default 1000. 0 = off
0x1018:01–04 | Identity | ro | Vendor, product, revision, serial
0x1200 | SDO server | ro | Rx 0x600+n, Tx 0x580+n
0x1400 / 1401 | RPDO1/2 communication | rw type | COB-ID and transmission type 255
0x1600 / 1601 | RPDO1/2 mapping | ro | Fixed mapping (see Part 4)
0x1800 / 1801 | TPDO1/2 communication | rw type | Cyclic/event while operational
0x1A00 / 1A01 | TPDO1/2 mapping | ro | Fixed mapping

### 2.5 Manufacturer objects (Grafito 0x2000 range)

These are not in the CiA 402 standard. Use SDO in pre-operational or operational. After changing node ID or bitrate, write 0x2008 = 1 (save) and reset the node.

Index | Name | Type | Default | Notes
0x2000 | Node ID | U8 | 1 | 1–127. Save + reboot to apply COB-IDs
0x2001 | Steps per revolution | U32 | 200 | Motor full steps
0x2002 | Microsteps | U32 | 16 | Power of two, 1–256
0x2003 | Run current % | U8 | 20 | 1–100 of TMC peak
0x2004 | Hold current % | U8 | 5 | 0–100
0x2005 | Stall threshold | U8 | 10 | TMC SGTHRS
0x2006 | Invert direction | U8 | 0 | Set 1 if closed loop runs the wrong way
0x2007 | Closed loop enable | U8 | 1 | 1 = encoder PID on position moves
0x2008 | Save config | U8 wo | — | Write 1 to persist NVS
0x2009 | Load defaults | U8 wo | — | Write 1; node ID kept
0x200A | StealthChop | U8 | 1 | 0 = SpreadCycle
0x200B | Standstill mode | U8 | 1 | 0 normal, 1 freewheel, 2 brake, 3 strong
0x200C | Endstop enable | U8 | 1 | GPIO8 / HOME
0x200D | Endstop active high | U8 | 1 | Pressed = GPIO8 HIGH
0x200E | CAN bitrate | U32 | 1000000 | 125000 / 250000 / 500000 / 1000000
0x200F–2011 | PID Kp / Ki / Kd | R32 | 10 / 0.3 / 0.35 | Closed-loop tracking (fw 2.1)
0x2012 | PID tolerance | R32 | 0.35 | Degrees
0x2013 | Enable on boot | U8 | 0 | Keep 0 so coils stay off until 402 enable
0x2014 | Zero on boot | U8 | 0
0x2015 | Homing timeout | U32 | 30000 | Milliseconds
0x2016 | Firmware version | U16 ro | 0x0201 | Major in high byte (2.1)
0x2017 | Encoder OK | U8 ro | 1
0x2018 | Endstop active | U8 ro | 0 | Logical HOME after polarity
0x2019 | Bus voltage | R32 ro | 24.0 | Reported rail; C3 has no VBUS ADC
0x201A | PID Ka | R32 | 0.04 | Acceleration feedforward (seconds)
0x201B | Profile jerk | R32 | 0 | Deg/s³; 0 = auto amax/0.05 s
0x201C | LUT enable | U8 | 0 | Requires valid table (0x201E)
0x201D | LUT command | U8 wo | — | 0 cal, 1 enable, 2 disable, 3 clear
0x201E | LUT valid | U8 ro | 0 | 1 after successful calibration
0x201F | LUT peak INL | R32 ro | 0 | Degrees

Invert direction (0x2006) On the first live CANopen bench, a +10° command ran the opposite way and faulted. Many GCSP boards were stored with INVERT_DIR=1. CANopen NVS is a new namespace, so invert defaults to 0. If the motor runs away from the target, set 0x2006 = 1, save, and retry a small move.

### 2.6 Tune gains from the PLC

Closed-loop command is v = v_ff + Ka · a_ff + PID(r − encoder). PID only trims lag. Cruise speed is 0x6081, not Kp. Write gain objects as REAL32 (IEEE-754). In TwinCAT / Codesys map them as REAL — do not write integer 10 into 0x200F.

Index | Name | Factory | What to change
0x200F | Kp | 10.0 | Stiffness. Raise if it lags; lower if it buzzes.
0x2011 | Kd | 0.35 | Damping. Raise if it rings at settle.
0x2010 | Ki | 0.3 | Steady-state. Keep small; too much → overshoot / 0x7122.
0x201A | Ka | 0.04 | Accel feedforward. Raise if it sags in accel/decel.
0x2012 | PID tolerance | 0.35° | Target-reached band. Too tight at high RPM → 0x7122.

Before PID: invert 0x2006, current 0x2003 30–40, closed loop 0x2007 = 1, velocity 0x6081, accel 0x6083. Save with 0x2008 = 1.

Order: enable 6 → 7 → 15; leave Ki/Ka at factory; step Kp by ~2 (8 → 10 → 12); if it oscillates raise Kd or drop Kp; then nudge Ka or Ki; save.

## Part 3 — Intermediate: CiA 402 drive profile Intermediate

### 3.1 Why a PLC will not move from “enable bit = 1”

CiA 402 uses a finite state machine. The PLC walks the drive through named states by writing the controlword (0x6040). The drive reports the state in the statusword (0x6041). Skipping steps is ignored.

State | Statusword bits 0–6 | Hex (plus remote 0x200) | Coils / motion
Switch on disabled | xxxx 0100 0000 | 0x0240 | Off after boot
Ready to switch on | xxxx 0010 0001 | 0x0231 | Still off
Switched on | xxxx 0010 0011 | 0x0233 | Power stage ready
Operation enabled | xxxx 0010 0111 | 0x0237 | Motion allowed
Quick stop active | xxxx 0000 0111 | 0x0207 | Stopping
Fault | xxxx 0000 1000 | 0x0208 | Disabled; need fault reset

Bit 4 (voltage enabled, 0x0010) and bit 9 (remote, 0x0200) are also set in the ready / enabled states on this firmware.

### 3.2 Controlword commands (0x6040)

The command is encoded in bits 0–3 and 7. Other bits (new setpoint, relative, halt) are used only in Operation enabled.

Command | Write value (typical) | Bits that matter | From → to
Shutdown | 0x0006 | xxxx x110 | SOD → Ready; OE → Ready
Switch on | 0x0007 | xxxx 0111 | Ready → Switched on; also “disable operation” from OE
Enable operation | 0x000F | xxxx 1111 | Switched on → Operation enabled
Disable voltage | 0x0000 | bit1 = 0 | Back to Switch on disabled
Quick stop | 0x0002 | xxxx x01x | OE → Quick stop
Fault reset | 0x0080 | bit7 rising edge | Fault → Switch on disabled
New setpoint (pp/hm) | 0x001F | 0x000F + bit4 | Starts a position or home
Halt | 0x010F | bit8 | Stop, target reached
Relative pp | 0x005F | bit6 + bit4 + 0x0F | Target is a delta

Memorise this enable sequence Write 0x6040 = 6, then 7, then 15 (0x0F). Read 0x6041 after each step until bits 0–6 equal 0x21, 0x23, then 0x27. Only then write a target.

### 3.3 Statusword extra bits

Bit | Mask | Meaning on this drive
10 | 0x0400 | Target reached (move finished or halt complete)
12 | 0x1000 | pp: set-point acknowledge / hm: homing attained
13 | 0x2000 | Following error (if raised)

### 3.4 Modes of operation (0x6060 / 0x6061)

Value | Name | How you command it
1 | Profile position (pp) | Write 0x607A, then set controlword new-setpoint bit
3 | Profile velocity (pv) | Write 0x60FF while enabled; 0 = stop
6 | Homing (hm) | Write 0x6098 method, then new-setpoint bit
0 | No mode | Idle

0x6502 (supported modes) = 0x00000025 (bit 0 = pp, bit 2 = pv, bit 5 = hm). Interpolated position, cyclic synchronous, and torque modes are not implemented.

### 3.5 Profile position recipe

1. Optional: set 0x6081 (cruise) and 0x6083 (accel) in counts/s and counts/s².
2. Write 0x6060 = 1.
3. Walk 6 → 7 → 15 on 0x6040.
4. Write 0x607A = target counts (absolute unless controlword bit 6 is set).
5. Write 0x6040 = 0x001F (enable + new setpoint).
6. Write 0x6040 = 0x000F (drop bit 4; leave enabled). Status bit 12 acks the edge.
7. Wait until 0x6041 bit 10 (target reached) or 0x6064 is inside tolerance.

### 3.6 Homing methods (0x6098)

Value | Behaviour
35 or 0 | Define current shaft position as zero (no motion)
17 | Seek HOME endstop, negative direction
18 | Seek HOME endstop, positive direction
−1 | StallGuard seek, negative (manufacturer)
−2 | StallGuard seek, positive (manufacturer)

Speeds: 0x6099:01 search, 0x6099:02 zero-window. Timeout: 0x2015. GPIO8 is a strapping pin — it must be HIGH at power-on or the ESP32-C3 may not boot.

### 3.7 Faults (0x603F and EMCY)

Code | Name | Typical cause
0x0000 | None
0x2310 | Short / overcurrent | TMC S2G or low-side short
0x4310 | Over-temperature | TMC OT shutdown
0x7305 | Encoder | SSI loss longer than 25 ms
0x7122 | Blocked / no progress | Closed loop not reducing error
0xFF01 | Homing failed | Timeout or illegal method

An EMCY frame is sent on 0x080 + node ID: bytes 0–1 = error code, byte 2 = error register. Recover with controlword fault reset (0x0080), then repeat 6 → 7 → 15.

## Part 4 — Advanced: PDOs, COB-IDs, SDO and bus timing Advanced

### 4.1 COB-ID map for node N

Standard 11-bit identifiers. Defaults below are for N = 1 as stored in the EDS. Live firmware adds the actual node ID.

Service | Formula | Node 1 | Direction
NMT | 0x000 | 0x000 | Master → all / one
SYNC | 0x080 | 0x080 | Master → slaves
EMCY | 0x080 + N | 0x081 | Node → master
TPDO1 | 0x180 + N | 0x181 | Status + position
RPDO1 | 0x200 + N | 0x201 | Controlword + target position
TPDO2 | 0x280 + N | 0x281 | Status + velocity
RPDO2 | 0x300 + N | 0x301 | Controlword + target velocity
TSDO (reply) | 0x580 + N | 0x581 | Node → master
RSDO (request) | 0x600 + N | 0x601 | Master → node
Heartbeat | 0x700 + N | 0x701 | Node → master (1 byte NMT state)

Heartbeat payload: 0x00 boot-up, 0x04 stopped, 0x05 operational, 0x7F pre-operational.

NMT payload (ID 0x000): byte0 = command (0x01 start, 0x02 stop, 0x80 pre-op, 0x81 reset node, 0x82 reset comm), byte1 = node ID or 0 for all.

Why GCSP and CANopen cannot share a bus GCSP uses CAN ID = (node_id << 6) | msg_id. That range collides with CANopen SYNC (0x080), EMCY, TPDOs and heartbeats. Flash one protocol per network.

### 4.2 PDO mapping encoding

Each mapping entry is a 32-bit value: bits 31–16 = index, 15–8 = subindex, 7–0 = bit length.

Object | Stored value | Decoded
0x1600:01 | 0x60400010 | Controlword 0x6040:00, 16 bits
0x1600:02 | 0x607A0020 | Target position 0x607A:00, 32 bits
0x1601:01 | 0x60400010 | Controlword, 16 bits
0x1601:02 | 0x60FF0020 | Target velocity, 32 bits
0x1A00:01 | 0x60410010 | Statusword, 16 bits
0x1A00:02 | 0x60640020 | Position actual, 32 bits
0x1A01:01 | 0x60410010 | Statusword, 16 bits
0x1A01:02 | 0x606C0020 | Velocity actual, 32 bits

RPDO1 payload (8 bytes): U16 controlword | I32 target_pos | U16 pad. RPDO2 replaces the I32 with target velocity. TPDOs use the same layout with statusword + actual value.

Transmission type 255 = event / manufacturer (async). Firmware also emits TPDOs about every 20 ms while NMT is operational. RPDOs are ignored unless the node is operational. Mapping is fixed in firmware; SDO writes to 0x1600/0x1A00 are read-only.

### 4.3 SDO protocol the EDS implies

All configuration objects are reached with expedited SDO except visible strings (0x1008/09/0A), which use segmented upload.

Request  ID 0x600+N
  cmd, index_lo, index_hi, sub, d0, d1, d2, d3

Upload request          cmd = 0x40
Expedited download 4 B  cmd = 0x23   (3 B 0x27, 2 B 0x2B, 1 B 0x2F)
Download OK             cmd = 0x60
Expedited upload 4 B    cmd = 0x43
Initiate segmented      cmd = 0x41 + size
Abort                   cmd = 0x80 + abort code

Common abort codes: 0x06020000 no object, 0x06090011 no subindex, 0x06010002 write to RO, 0x06090030 value rejected (bad bitrate, non-power-of-two microsteps, illegal mode).

### 4.4 NMT vs 402 — two state machines

Beginners mix these up. They are independent:

- NMT (network): boot → pre-op (SDO yes, PDO no) → operational (SDO + PDO) → stopped (almost mute) → reset.
- 402 (drive): switch-on-disabled → … → operation enabled / fault.

You can SDO-enable the 402 machine while still in NMT pre-op (useful for commissioning). Cyclic RPDO motion only works after NMT Start (0x01).

### 4.5 Editing the EDS (when you are allowed)

Safe edits: comments, ParameterName text, FileRevision, description. Dangerous edits: removing an object the firmware still implements, changing DataType, or advertising a PDO map the stack does not use. After any object change, regenerate EDS, DCF and the object-dictionary exports together with write_canopen_descriptions() so the Python tests, PLC files and firmware stay aligned.

DummyUsage Dummy0002–0007 = 1 lets tools pad PDO slots. Leave as shipped.

## Part 5 — Advanced: PLC import and first-motion recipes Advanced

### 5.1 Wiring and tool setup (all brands)

1. Flash GrafitoCANStepper_C3_CANopen (Arduino FQBN esp32:esp32:esp32c3:CDCOnBoot=cdc).
2. Apply Vin 5–24 V (typically 24 V). USB-C does not power the MCU for reliable programming or motion.
3. CAN: twisted pair, 120 Ω only on the two physical ends. On-board 0 Ω termination jumper is fitted by default — remove it on mid-chain boards.
4. PLC CAN adapter: 1 Mbps, 11-bit, no 29-bit, same ground reference.
5. Import GrafitoCANStepper.eds as the device type. If the tool wants a configured node / DCF, import GrafitoCANStepper_Node1.dcf (node 1, 1 Mbps). For another node ID, regenerate the DCF — do not reuse node 1 COB-IDs.
6. Set slave node ID to the value stored on the board (default 1).
7. Scan / go online. Read 0x1018. If vendor/product mismatch, you have the wrong EDS or the wrong firmware.

### 5.2 Codesys (CAN bus + CiA 405 / 3S CANopen)

1. Add a CANopen Manager under the CAN interface. Bitrate 1000 kbit/s.
2. Right-click manager → Add Device → Install vendor EDS → select GrafitoCANStepper.eds.
3. Add “Grafito CANStepper C3” as a slave. Node ID 1. Heartbeat consumer 1.5× 1000 ms is a good watchdog.
4. Map RPDO1 (controlword + target pos) and TPDO1 (statusword + position) into your IEC program as integers.
5. Startup SDO list (optional): 0x2003 run current, 0x2006 invert, 0x200C endstop, 0x6081 speed, 0x6060 = 1.
6. NMT Start is usually sent by the manager automatically.

### 5.3 TwinCAT 3 (Beckhoff)

1. I/O → Devices → CAN → right-click → Import EDS.
2. Insert the box, set Node ID and 1 Mbaud on the adapter (EL6751, FC510x, CX CAN, …).
3. Process data tab should show the four PDOs. Create PLC variables linked to 0x6040, 0x6041, 0x607A, 0x6064.
4. Free-run or start the NC/PLC. Use a small state machine FB: shutdown / switch on / enable / new setpoint.

### 5.4 TIA Portal / other Siemens CAN (via gateway)

S7-1200/1500 do not speak CiA 402 natively on a random CAN dongle. Typical paths: a dedicated CANopen master (HMS, Ixxat, Siemens CM CANopen) that imports the EDS, or a Linux SoftPLC (Codesys) as gateway. Import the same EDS on that master. Do not expect a raw “CAN_SEND” FB to honour the 402 state machine unless you write it yourself.

### 5.5 IEC-style enable and jog (pseudocode)

VAR
  cw AT %QW : UINT;     (* 0x6040 via RPDO1 *)
  sw AT %IW : UINT;     (* 0x6041 via TPDO1 *)
  tgt AT %QD : DINT;    (* 0x607A *)
  pos AT %ID : DINT;    (* 0x6064 *)
  step : INT;
END_VAR

CASE step OF
  0: cw := 16#0006; IF (sw AND 16#006F) = 16#0021 THEN step := 1; END_IF
  1: cw := 16#0007; IF (sw AND 16#006F) = 16#0023 THEN step := 2; END_IF
  2: cw := 16#000F; IF (sw AND 16#006F) = 16#0027 THEN step := 3; END_IF
  3: tgt := pos + 455;  (* +10 degrees *)
     cw := 16#001F;     (* new set-point *)
     step := 4;
  4: cw := 16#000F;     (* drop bit 4 *)
     IF (sw AND 16#0400) <> 0 THEN step := 5; END_IF
  5: (* dwell / next move *)
END_CASE

IF (sw AND 16#0008) <> 0 THEN  (* fault *)
  cw := 16#0080; step := 0;
END_IF

### 5.6 USB serial bridge (no PLC, same objects)

Firmware still prints and accepts hex lines: <CAN_ID hex> <0|1> <payload hex>. Opening the USB-JTAG port resets the C3 — wait for # CAN started and heartbeat 0x7F.

python3 tools/canopen_bringup.py /dev/ttyACM0 --node 1
# identity only; add --move-deg only after invert is verified

Example SDO read of device type on node 1:

601 0 4000100000000000
# expect 581 0 4300100092010400   → 0x00040192

### 5.7 Recommended first-commission checklist

1. Read 0x1000, 0x1018, 0x2016, 0x2017 (encoder OK).
2. If 0x2018 (endstop) is 1 and you are not at a real home, write 0x200C = 0 for the first jog.
3. Set 0x2003 to a modest current (30) and 0x6081 to ~2275 (~50 °/s).
4. Enable 402. Confirm 0x6041 = 0x0237. Coils should hold; shaft should not run.
5. Command +455 counts. If the encoder moves the other way, abort, set 0x2006 = 1, save, reset, retry.
6. Only then raise speed/current and switch to RPDO cyclic control.

## Part 6 — Reference tables and troubleshooting Advanced

### 6.1 Full CiA 402 object list in this EDS

Index | Name | Type | Access | PDO | Default
0x603F | Error Code | U16 | ro | no | 0
0x6040 | Controlword | U16 | rw | yes | 0
0x6041 | Statusword | U16 | ro | yes | 0x0240
0x605A | Quick Stop Option Code | I16 | rw | no | 2
0x6060 | Modes of Operation | I8 | rw | yes | 1
0x6061 | Modes of Operation Display | I8 | ro | yes | 1
0x6064 | Position Actual Value | I32 | ro | yes | 0
0x606C | Velocity Actual Value | I32 | ro | yes | 0
0x607A | Target Position | I32 | rw | yes | 0
0x6081 | Profile Velocity | U32 | rw | no | 32768
0x6083 | Profile Acceleration | U32 | rw | no | 65536
0x6084 | Profile Deceleration | U32 | rw | no | 65536
0x6085 | Quick Stop Deceleration | U32 | rw | no | 262144
0x6098 | Homing Method | I8 | rw | no | 35
0x6099:1/2 | Homing speeds | U32 | rw | no | 2275 / 455
0x609A | Homing Acceleration | U32 | rw | no | 131072
0x60FF | Target Velocity | I32 | rw | yes | 0
0x6502 | Supported Drive Modes | U32 | ro | no | 0x25

### 6.2 What this EDS does not claim

- No CiA 402 interpolated position (mode 7), cyclic synchronous position/velocity, or torque mode.
- No safety (STO, CiA 402 Safety / FSoE).
- No LSS node-ID assignment over CAN.
- No dynamic PDO remapping.
- No official CiA vendor ID yet (0x5A3 is a placeholder).
- Leader/follower (GCSP FOLLOW) is not exposed in CANopen.

### 6.3 Troubleshooting

Symptom | Likely cause | What to do
EDS import fails | Wrong encoding, missing object list | Use the generated file as-is; ASCII only
Scan finds nothing | Wrong bitrate, termination, GCSP still flashed | Confirm boot line “CANopen fw 2.1”, 1 Mbps, 120 Ω
SDO abort 0x06020000 | Tool writing an object not in this subset | Disable that object in the PLC device
PDOs silent | NMT still pre-op | Send NMT Start 0x01
Enable does nothing | Skipped 6→7→15 | Read 0x6041 after each write
Move runs away / faults 0x7122 | Invert or encoder magnet | 0x2006 = 1; check 0x2017; lower 0x6081
Node dead after power-up | GPIO8 held LOW at reset | HOME must be HIGH at boot (strapping)
USB open reboots the chip | USB-JTAG DTR/RTS | Hold DTR/RTS off; wait for heartbeat 0x7F
Old Python library fails | GCSP IDs vs CANopen IDs | Use canopen402 / a PLC, not canstepper GCSP

### 6.4 Regenerating the EDS, DCF and object dictionary

cd can_stepper
python3 -c "from canstepper.canopen402 import write_canopen_descriptions; print(write_canopen_descriptions())"
python3 -m pytest tests/test_canopen.py

The pytest suite checks that every object in the Python dictionary appears in the EDS and DCF, that the DCF has DeviceComissioning + ParameterValue, that the JSON/CSV catalogues match, that identity constants match the firmware header, and that a virtual slave performs NMT, SDO, 402 enable, PDOs and homing.

### 6.5 Learning path (use this document in order)

1. Part 1 until you can explain EDS vs firmware vs CAN wire.
2. Flash 2.1 and read 0x1000 / 0x1018 (USB script or PLC scan).
3. Part 3: perform 6 → 7 → 15 and watch 0x6041.
4. One 10° move with low 0x6081 after invert is confirmed.
5. Part 4: switch the same move onto RPDO1 / TPDO1.
6. Part 5: import the shipped DCF (or regenerate for another node ID) and lock startup SDOs on the customer PLC.

Document generated for Grafito CANStepper C3 firmware 2.1, GrafitoCANStepper.eds (EDS 4.0) and GrafitoCANStepper_Node1.dcf.
Companion files: object_dictionary.json / .csv, canopen_stack.h, canopen402.py, tools/canopen_bringup.py.
Standards referenced: CiA 301 (application layer), CiA 306 (EDS/DCF), CiA 402 (drives). Grafito implements a subset, not a full certified stack.

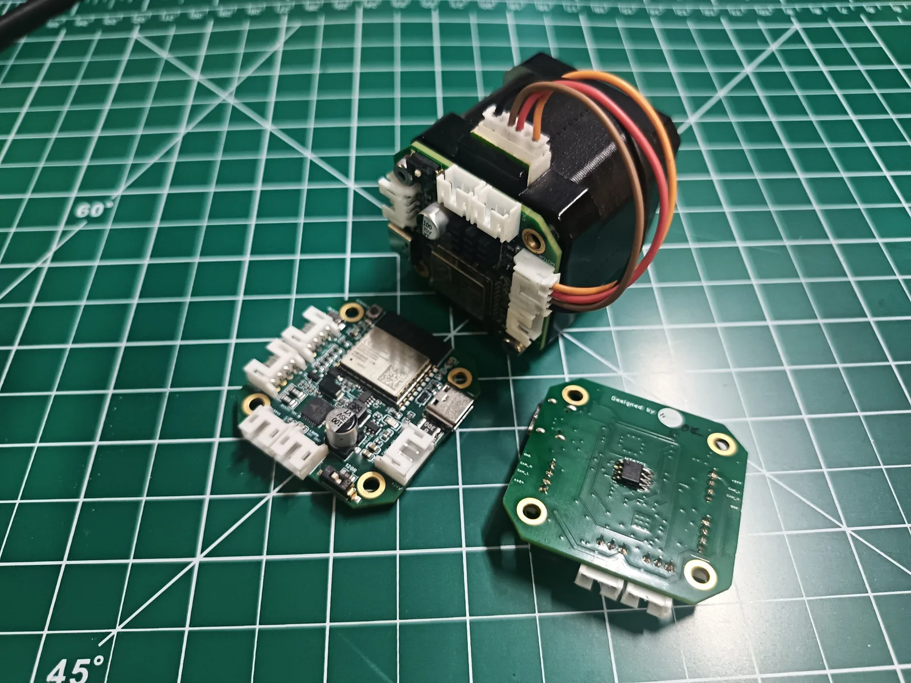
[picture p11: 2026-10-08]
model_assets/CANStepper_V2_Assembly.webp

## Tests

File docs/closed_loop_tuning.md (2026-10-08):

# Closed-loop speed tuning (firmware ≥1.11)

This guide explains how closed-loop position moves work on Grafito CANStepper
(7-segment S-curve + acceleration feedforward + optional 200-step encoder LUT),
why open-loop `run()` can still look “faster,” the physical RPM ceiling, and
**measured settle / overshoot error** on a real NEMA 17 motor (model below).

Related docs: [quickstart](quickstart.md) · [protocol](protocol.md) ·
[Klipper kinematics (background)](https://www.klipper3d.org/Kinematics.html)

---

## 0. Device under test (characterization motor)

All tables and soak numbers in this document were measured on the following
stepper (unless a section explicitly says otherwise). Results will scale with
supply voltage, mechanical load, and reflected inertia — re-validate on your
mechanism.

### Motor

| Item | Spec |
|---|---|
| **Type** | NEMA 17 stepper motor |
| **Model No.** | **PR42HS40-1204AF-02** |
| **Step angle** | 1.8° (200 full steps/rev) |
| **Shaft** | D-type |
| **Shaft diameter** | 4.5 mm |
| **Shaft length** | 19 mm |
| **Frame size** | 42 × 42 mm |
| **Motor length** | 40 mm |
| **Phases** | 2 |
| **Lead wires** | 4 |
| **Rated current** | **1.2 A** |
| **Holding torque** | 4.2 kg·cm |
| **Detent torque** | 0.22 kg·cm |
| **Inductance** | **3.2 mH** (low-inductance → good high-speed headroom on 24 V) |
| **Rotor inertia** | 54 g·cm² |
| **Net weight** | 250 g |
| **Shipping weight** | 0.283 kg |
| **Shipping dimensions** | 7 × 6 × 6 cm |

### Controller / drive stack

| Item | Spec |
|---|---|
| Board | Grafito CANStepper (ESP32-C3 + TMC2209 + MT6701 + CAN) |
| Firmware | **GCSP v1, fw 1.11 / 1.12** (S-curve + Ka + 200-step LUT). fw 1.2 soak kept below as history. |
| Encoder | MT6701 magnetic, 14-bit SSI + 200-step LUT (peak INL 2.12°) |
| Driver | TMC2209 UART, SpreadCycle for high-speed tests |
| Bus supply | **24.0 V** measured under load |
| USB | CDC bridge on the same node under test |
| Node | **3** (USB, MAC A0) for fw 1.11 error/RPM tables; older 1.2 soak was node 1 |

### What was tested

1. Current × cruise matrix (40–100%, up to 6000 deg/s CL)
2. Microsteps 4 / 8 / 16
3. StealthChop vs SpreadCycle
4. Open-loop velocity ladder to 7200 deg/s
5. Focused **100% current** OL + CL ladders + 5× burst
6. **10-minute continuous closed-loop soak** at production tune (70% / 4800)

---

## 1. Motion profiles: what the firmware actually does

| Mode | Profile | Encoder? | Settles on target? |
|---|---|---|---|
| `run(v)` open-loop velocity | Accel ramp → constant speed | No | No — spins forever |
| `move_to` open-loop | **Trapezoid** (FastAccelStepper) | No (step count) | Step target only |
| `move_to` closed-loop **≥1.11** | **7-segment S-curve + v_ff + Ka·a_ff + tracking PID** | Yes (+ LUT) | Yes → `MOVE_DONE` |
| FOLLOW (encoder-corrected) | Continuous braking-law chase | Yes | Holds leader |

Open-loop position still uses FastAccelStepper’s **constant-acceleration**
trapezoid. Closed-loop ≥1.11 is jerk-limited (S-curve). `cl_max_jerk = 0`
means auto jerk `amax / 0.05 s`.

### Closed-loop ≥1.11 control law

On every `MOVE_ABS` / `MOVE_REL` with `closed_loop=1`:

```
1. Plan rest-to-rest 7-segment S-curve:
      vmax = min(max_speed, cl_max_speed)
      amax = cl_max_accel
      jerk = cl_max_jerk or amax/0.05
      from encoder angle → target

2. Each 5 ms (200 Hz):
      r(t), v_ff(t), a_ff(t)  = evaluate S-curve
      e_track                 = r(t) − encoder (LUT-corrected)
      v_cmd                   = v_ff + Ka·a_ff + Kp·e_track + Ki·∫ − Kd·v_meas

3. Settle when:
      plan finished AND |target − encoder| ≤ pid_tolerance
      AND |v_meas| is low  →  emit MOVE_DONE
```

Velocity diagram of a long move:

```
  v
  ^
  |     /----------\        ← cruise at cl_max_speed
  |    /            \
  |   /              \
  +-----------------------> t
    accel   cruise   decel
```

Short moves never reach cruise (triangle): accel immediately becomes decel.

This matches the classic “trapezoid generator” described in Klipper’s
kinematics docs, plus encoder tracking so the shaft actually arrives.

### Why pure PID (pre-1.1) failed at high speed

With `v = Kp · error` only, stopping from cruise needs roughly `v/Kp`
degrees of residual error. At 2000 deg/s and Kp=6 that is ~300° of overshoot
→ reverse → hunt → `NO_PROGRESS` or never settle. Raising `cl_max_speed`
alone made it worse.

Firmware 1.2 **plans the deceleration**, so the feedforward already slows
before the target; the PID only trims lag/load.

### Why open-loop `run()` can still look faster

| Mode | Must decelerate? | Must settle on encoder? |
|---|---|---|
| Open-loop continuous velocity | No | No |
| Closed-loop position | Yes | Yes |

On this motor @ 24 V the **open-loop** ceiling is ~**3000 RPM**. Closed-loop
precision work should stay at 120 RPM / 1440 deg/s²; pushing CL cruise toward
the OL ceiling still has to decelerate and settle, and 100% current trips
TMC **fault=4** (over-temperature).

---

## 2. Parameters that matter

| Param | Role in CL ≥1.11 | Precision default (this motor, fw 1.12) |
|---|---|---|
| `cl_max_speed` | S-curve **cruise** vmax (deg/s) | **720** (120 RPM) |
| `cl_max_accel` | S-curve peak accel (deg/s²) | **1440** |
| `cl_max_jerk` | Jerk limit (deg/s³); 0 = auto | **0** |
| `pid_ka` | Accel feedforward (seconds) | **0.04** |
| `max_speed` / `acceleration` | Also used as plan caps / open-loop | Match CL values |
| `pid_kp/ki/kd` | Tracking trim around `v_ff + Ka·a_ff` | **10 / 0.3 / 0.35** |
| `pid_tolerance` | Settle window (deg) | **0.35** |
| `lut_enable` | Apply 200-step encoder LUT | **1** after calibration |
| `run_current` | % of driver max | **40%** precision; **80%** OL speed tests |
| `microsteps` | Smoothness vs torque at speed | **8** precision; **2** for ~3000 RPM OL |
| `stealthchop` | 0 = SpreadCycle | **0** (required for high speed) |

One-shot setup:

```python
node.set_direction(True)   # if closed loop previously ran away
node.calibrate_encoder_lut()
node.configure_closed_loop_speed(
    720.0,
    accel_deg_s2=1440.0,
    run_current=40,
    microsteps=8,
    stealthchop=False,
    persist=True,
)
```

---

## 3. Physics limits (what actually caps RPM)

Independent of firmware (see also [JLCMC stepper speed notes](https://jlcmc.com/blog/stepper-motor-speed)):

1. **Supply voltage** — higher V forces current into inductive windings against back-EMF. We test at **24 V**.
2. **Current** — more torque; on this 1.2 A motor, TMC % is relative to driver max. Continuous 70% was more reliable than hammering 100% without cool-down.
3. **Inductance & back-EMF** — this motor’s **3.2 mH** inductance is friendly to high speed; higher-L motors sag earlier.
4. **Rotor inertia (54 g·cm²)** — sets acceleration authority with available torque.
5. **Microstepping** — 8× for precision; **2×** is the OL ~3000 RPM sweet spot (1× was less consistent above 2500 RPM).
6. **Chopper mode** — **SpreadCycle** holds torque at speed; **StealthChop** is quiet but sags early.
7. **Resonance** — mid-band can stall open-loop; closed-loop recovers better.
8. **USB / CDC link** — aggressive 100% continuous motion once dropped CDC (`/dev/ttyACM0` vanished); treat as a system limit when USB data and high motor current share a node (logic is from Vin, not USB power).

Practical ceiling observed on this motor @ 24 V (firmware velocity, 2 µsteps,
80% current, SpreadCycle): open-loop **~3000 RPM** (100% of command).
**3300 RPM** starts to sag (~93%). **3500–4000 RPM** loses steps.
**5000 RPM is not reachable**. 100% current can match 3000 RPM briefly, then
TMC **OT (`fault=4`)**. Closed-loop precision settle stays at 120 RPM / 1440
accel; do not persist high-speed current/µstep into NVS for positioning work.

---

## 3.1 Firmware 1.11 confirmation run (error results)

**2026-10-08**, node 3 USB, fw **1.11**, Vin **24.0 V**, MCU **42 °C**, LUT
valid (200 points, peak INL **2.116°**), LUT enabled. Precision NVS:
`I=40%`, 8 µstep, SpreadCycle, `cl_max_speed=720`, `cl_max_accel=1440`,
auto jerk, `Kp=10`, `Ki=0.3`, `Kd=0.35`, `Ka=0.04`, `tol=0.5°`.

Hold at zero for 2 s: **0.000° peak-to-peak**.

| Move (deg) | Overshoot (deg) | Settle error (deg) | \|err\| (deg) | Time (s) |
|---|---|---|---|---|
| +30 | 0.081 | +0.125 | **0.125** | 1.02 |
| +45 | 0.044 | +0.176 | **0.176** | 1.02 |
| +90 | 0.088 | +0.110 | **0.110** | 1.17 |
| +180 | 0.000 | +0.132 | **0.132** | 1.32 |
| −45 | 0.000 | +0.044 | **0.044** | 1.02 |
| −90 | 0.000 | +0.088 | **0.088** | 1.17 |
| +360 | 1.560 | +0.286 | **0.286** | 1.77 |
| +720 | 0.066 | +0.066 | **0.066** | 2.08 |
| +1080 | 0.132 | +0.198 | **0.198** | 2.53 |

**Closed-loop summary (9/9 settled):** median \|err\| **0.125°**, max **0.286°**;
median overshoot **0.066°**, max **1.560°** (one-rev). Earlier trap-only 180°
moves overshot ~43°; S-curve + Ka + LUT brought 180° overshoot to **0.000°**.

Open-loop `run()` firmware-velocity ladder (temporarily 2 µstep, 80% current;
precision NVS restored afterward):

| Command RPM | Firmware median RPM | Reach |
|---|---|---|
| 2000 | 2000 | 100% |
| 2500 | 2494 | 100% |
| **3000** | **2977** | **99%** |
| 3300 | 3075 | 93% |
| 3500 | 1321 | 38% |
| 4000 | 1607 | 40% |
| **5000** | **35** | **1% — not reachable** |

Parameter scan notes (same motor): `Kp=10 / Kd=0.35 / Ka=0.04` is the
reliable stop-on-target set. `Kp=12` / high accel (≥180000 deg/s²) and
**100% current** trip **FAULT4 (OT)**. Softer `Kp=6` times out on long fast
moves. [arabel1a/S-curve-stepdir](https://github.com/arabel1a/S-curve-stepdir)
is a GPL AVR pulse-table profiler (`f_0` start speed, slowest accel that still
guarantees a cruise band). We already do on-the-fly S-curve on ESP32-C3; `f_0`
would help first-step pull-in, not the 5000 RPM back-EMF wall. Do not copy
that repo into this tree.

---

## 4. Hardware matrix results (historical, fw 1.2 trap)

**Conditions (default):** firmware 1.2, 24 V, PR42HS40-1204AF-02, node 1,
`invert_dir=1`, SpreadCycle, tracking PID 12 / 0.3 / 0.10, tol=0.35°,
accel = 4× cruise. Move length noted per subsection.

### 4.1 Current × cruise (microsteps = 8, move = 2160°)

| I% | 720 | 1440 | 2160 | 3600 | 4800 | 6000 deg/s |
|----|-----|---|---|---|---|---|
| 40 | OK  | OK | OK | OK | OK | OK |
| 55 | OK  | OK | OK | OK | OK | OK |
| 70 | OK  | OK | OK | OK | OK | OK |
| 85 | OK  | OK | OK | OK\* | OK | OK\* |
| 100 (early matrix) | timeout | timeout | OK | OK | OK\* | OK\* |

\* Sometimes longer settle or lower peak (inconsistent).

**Peak encoder speeds while settling (typical 70%):**

| Cruise (deg/s) | Peak (deg/s) | Peak RPM | Settle time (2160°) |
|---|---|---|---|
| 720 | ~1150 | ~190 | ~4–5 s |
| 1440 | ~2250 | ~375 | ~2.5 s |
| 2160 | ~3300 | ~550 | ~1.9 s |
| 3600 | ~4600–5000 | ~800 | ~1.5 s |
| 4800 | ~6000–6600 | ~1000–1100 | ~1.3–1.4 s |
| 6000 | ~7200–7500 | ~1200–1250 | ~1.3 s |

**Confirmatory re-run (70%, 8 µstep):** 3600 / 4800 / 6000 all OK; peaks
4638 / 6594 / 7174 deg/s.

### 4.2 Focused 100% current retest (after USB recovery)

A dedicated 100% session (with cool-downs between rungs, move = **1440°**)
showed **better** behavior than the first matrix pass:

**Open-loop @ 100%**

| cmd | result |
|-----|---|
| 360 → **7200** deg/s | all **tracking** (ratio ≈ 1.0) |

Reliable OL ceiling @ 100%: **~7200 deg/s (1200 RPM)**.

**Closed-loop @ 100%**

| cruise | result | notes |
|---|---|---|
| 360 … **6000** | all **OK** | peaks up to ~6260 deg/s |
| Burst 5× @ 6000 | **5/5 OK** | peaks ~6100–6160 |

**Caveats observed at 100%:**

- An earlier 100% session **dropped USB** mid-ladder (serial I/O error, then
  `/dev/ttyACM0` gone) — brownout / CDC reset under high motor current.
- First matrix pass had low-speed CL timeouts at 100%; second pass did not.
  Treat 100% as **possible for short bursts**, not as the default continuous
  duty without thermal and USB margin.

MCU rose ~33 → 44 °C during the successful 100% ladder; Vbus held 24.0 V.

### 4.3 Microsteps @ 85% current

| µsteps | 1440 | 3600 | 4800 | 6000 |
|---|---|---|---|---|
| 4 | OK (slow) | timeout | OK | timeout |
| **8** | OK | **OK** | **OK** | **OK** |
| 16 | OK (slow) | OK | OK | OK |

**8 microsteps** is the most consistent high-speed choice on this motor.
4× is resonance-sensitive. 16× works but often slower settle at mid cruise.

### 4.4 StealthChop vs SpreadCycle (70%, 8 µstep)

| Mode | 720 | 1440 | 3600 | 4800 | Notes |
|---|-----|---|---|---|---|
| StealthChop | timeout | OK | OK (peak~3k) | OK (peak~1.8k) | Quiet; weak at speed |
| **SpreadCycle** | **OK** | **OK** | **OK peak~5k** | **OK peak~6.2k** | Required for high CL cruise |

### 4.5 Open-loop velocity ceiling (summary)

| Current | Reliable tracked `run()` ceiling | Notes |
|---|---|---|
| 70% | **~7200 deg/s** (1200 RPM) | Clean tracking |
| 100% (good run) | **~7200 deg/s** | With cool-downs |
| 100% (bad run) | stall by ~2160 | Thermal / supply / state dependent |

Closed-loop position with planned decel: **4800–6000 deg/s** cruise is proven
on this motor — about **0.7–0.8×** continuous open-loop ceiling.

---

## 5. Long-duration closed-loop soak (10 minutes)

Production-style reliability check on **PR42HS40-1204AF-02**.

| Item | Value |
|---|---|
| Duration | **10.00 minutes** continuous |
| Firmware | 1.2 |
| Tune | **70%** current, **4800** deg/s cruise, 8 µstep, SpreadCycle, accel=19200 |
| Pattern | `0° → 1440° → 0°` (two encoder settles per full cycle) |
| Tracking PID | kp=12, ki=0.3, kd=0.10, tol=0.35° |
| `invert_dir` | 1 |

### Results

| Metric | Value |
|---|---|
| Full cycles (A→B) | **239** |
| Total settles | **478** |
| **Success rate** | **100.00%** (478/478) |
| Faults (`NO_PROGRESS` / encoder) | **0** |
| Timeouts | **0** |
| USB / transport errors | **0** (0 reconnects) |
| Settle time min / median / max | **1.09 / 1.15 / 3.91 s** |
| Peak speed min / median / max | **1589 / 5658 / 6014 deg/s** |
| \|final − target\| median / max | **0.110° / 0.461°** |
| MCU temp start → end | **41.4 → 61.4 °C** (steady climb, no runaway) |
| Vbus start → end | **24.0 → 24.0 V** |

Progress samples stayed at **100% success** from cycle 1 through 230+. Near
the end a few moves ran slower (peak ~1600 deg/s, dt ~3.7 s) but still
settled inside tolerance — no faults.

### Observation

On this NEMA 17 (1.2 A, 3.2 mH, 4.2 kg·cm), **closed-loop trap + v_ff at
70% / 4800 deg/s is stable for continuous multi-minute duty**: no missed
settles, no USB loss, bus voltage flat, MCU thermal rise ~20 °C over 10 min
of continuous high-speed reversing moves.

---

## 6. Recommended production settings

Validated on: **PR42HS40-1204AF-02** + Grafito CANStepper C3, TMC2209,
MT6701, **24 V**, firmware **1.2**, `invert_dir=1`.

```python
from canstepper import CANStepperBus

bus = CANStepperBus.serial("/dev/ttyACM0")
node = bus.node(1)

node.set_direction(True)   # required on the characterized wiring
node.configure_closed_loop_speed(
    cruise_deg_s=4800.0,   # 800 RPM — margin under 6000 max proven
    run_current=70,        # continuous; 100% OK for short bursts only
    microsteps=8,
    stealthchop=False,     # SpreadCycle
    accel_factor=4.0,       # cl_max_accel = 19200
    kp=12.0, ki=0.3, kd=0.10,
    tolerance_deg=0.35,
    persist=True,
)
node.enable()
node.set_zero()
node.move_to(720.0, blocking=True)
```

| Goal | Suggested cruise | Current | Notes |
|---|---|---|---|
| Quiet / light duty | 720–1440 | 40–55% | StealthChop OK only at low speed |
| **Balanced production** | **4800** | **70%** | **Persisted default; 10 min soak PASS** |
| Absolute max (validated) | 6000 | 70–100% short | Re-check warm; cool-down between bursts @ 100% |
| Continuous 100% | not recommended as default | 100% | USB drop risk; prefer 70% for long duty |

To ship max cruise after soak:

```python
node.configure_closed_loop_speed(6000, run_current=70, microsteps=8,
                                 stealthchop=False, persist=True)
```

---

## 7. Key observations (checklist)

1. **Firmware 1.2 trap + v_ff** is required for high closed-loop cruise with
   reliable settle; pure PID (≤1.0) and braking-only (1.1) are inferior.
2. **This motor (PR42HS40-1204AF-02)** with 3.2 mH / 1.2 A on **24 V** can
   open-loop track ~**1200 RPM** and closed-loop cruise ~**800–1000 RPM**.
3. **Polarity matters:** `invert_dir=1` on the test wiring so encoder angle
   increases with positive commands; wrong polarity → `NO_PROGRESS`.
4. **SpreadCycle** beats StealthChop above a few hundred deg/s.
5. **8 microsteps** is the sweet spot; 4× resonance; 16× slower mid-band settle.
6. **70% continuous** is the production sweet spot (soak 100% success).
7. **100% current** can match high speed in short tests but has shown **USB
   disconnects** and earlier inconsistent low-speed CL timeouts — use for
   bursts with cool-down, not as silent always-on default.
8. **10 min soak** at 70%/4800: **478/478** settles, peak med ~5658 deg/s,
   final error med **0.11°**, MCU +20 °C, Vbus flat.
9. Closed-loop position is **not** expected to match continuous open-loop
   `run()` ceiling; plan for accel + decel + settle overhead.
10. Host helpers `plan_trapezoid` / `eval_trapezoid` mirror firmware planning
    for multi-axis timing (`MotionGroup`).

---

## 8. Tuning procedure (your machine)

1. **Polarity** — slow closed-loop move. If it runs away →  
   `node.set_direction(True); node.save_config()`.
2. **Driver baseline** — SpreadCycle, 8 µstep, 70% current, 24 V solid supply.
3. **Ladder**  
   ```bash
   python3 tools/cl_speed_validate.py /dev/ttyACM0 1 70 8
   python3 examples/closed_loop_speed.py /dev/ttyACM0 1   # sweep
   python3 tools/cl_matrix.py /dev/ttyACM0 1 --quick
   ```
4. **Pick last OK cruise** with margin (e.g. if 6000 works, ship 4800).
5. **Persist** with `configure_closed_loop_speed(..., persist=True)`.
6. **Thermal** — multi-minute continuous moves; if motor case is very hot or
   MCU climbs hard without plateau, drop current 10%.
7. **Load** — retune with real mechanism attached; reflected inertia lowers
   usable accel first, then cruise.
8. **Long soak** — run continuous A↔B moves for ≥10 min at the chosen cruise
   before locking production config.

### If settle fails

| Symptom | Try |
|---|-----|
| `NO_PROGRESS` immediately | `invert_dir`; check encoder OK bit |
| Timeout near target | Raise `pid_tolerance` slightly (0.35→0.5); raise `kd` a little |
| Stall mid-move | Raise current toward 85%; lower microsteps 16→8; ensure SpreadCycle |
| Works OL, fails CL | Confirm fw ≥1.2; raise `cl_max_accel` |
| Loud mid-band | Change µsteps; raise accel to punch through resonance |
| USB disconnect under load | Drop continuous current (e.g. 100%→70%); check 24 V bulk capacitance |

### Tracking PID notes (fw ≥1.2)

From a **PLC** (CANopen 2.1) the same gains are REAL32 objects: **0x200F** Kp,
**0x2010** Ki, **0x2011** Kd, **0x201A** Ka, **0x2012** tolerance. See
[canopen.md](canopen.md#tune-gains-from-the-plc).

Feedforward carries the move. PID only trims lag:

- **Raise Kp** if the shaft lags the plan (tracking error large in MOTION tel).
- **Raise Kd** if it rings at the end of decel.
- **Ki** small; too much causes slow oscillation around target.
- Do **not** treat Kp as the primary speed knob — that is `cl_max_speed`.

---

## 9. Library helpers

```python
# Host-side trap math (same equations as firmware trajPlan / trajAdvance)
from canstepper.kinematics import plan_trapezoid, eval_trapezoid, trapezoid_time

v_peak, t_acc, t_cruise, t_dec, t_tot = plan_trapezoid(
    distance=720.0, speed=4800.0, accel=19200.0
)
s, v_ff = eval_trapezoid(720.0, 4800.0, 19200.0, t=t_acc)  # end of accel
```

`MotionGroup` uses the same trapezoid **duration** math so multi-axis
point-to-point moves finish together (not continuous look-ahead/contouring).

---

## 10. Validation commands

```bash
cd ~/Grafito-Edge-Services/can_stepper

python3 -m pytest                              # sim unit tests
python3 tools/cl_speed_validate.py /dev/ttyACM0 1 70 8
python3 tools/cl_matrix.py /dev/ttyACM0 1 --quick
python3 examples/closed_loop_speed.py /dev/ttyACM0 1 4800
python3 examples/high_speed_test.py /dev/ttyACM0 1 70
python3 tools/hw_validate.py /dev/ttyACM0 1
```

Flash firmware 1.2+:

```bash
export PATH="$HOME/.local/bin:$PATH"
arduino-cli compile --fqbn esp32:esp32:esp32c3:CDCOnBoot=cdc \
  firmware/GrafitoCANStepper_C3
arduino-cli upload -p /dev/ttyACM0 --fqbn esp32:esp32:esp32c3:CDCOnBoot=cdc \
  firmware/GrafitoCANStepper_C3
```

---

## 11. Version history (closed-loop)

| FW | Closed-loop behaviour |
|----|---|
| ≤1.0 | Pure PI/D velocity chase; default cl_max_speed 30 deg/s |
| 1.1 | Braking-envelope cap on PI/D (no planned cruise) |
| **1.2** | **Trapezoidal trajectory + velocity feedforward + tracking PID** |
| **1.10** | **200-step MT6701 encoder LUT** (calibrate, persist, interpolate) |
| **1.11** | **7-segment S-curve + acceleration feedforward (`pid_ka`)** |
| **1.12** | Factory defaults from the 1.11 bench: accel 1440, Kp 10, Kd 0.35, Ka 0.04 |

---

## 12. What we did *not* implement (future)

| Idea | Source | Status |
|---|---|---|
| S-curve / jerk limit | JLCMC, machine tools | **Done (fw 1.11)** |
| Encoder LUT | MT6701 detent INL | **Done (fw 1.10)** |
| Accel feedforward Ka | S-curve a_ff | **Done (fw 1.11)** |
| Start speed `f_0` | arabel1a S-curve-stepdir | Not yet — optional pull-in, not a 5000 RPM fix |
| Look-ahead / junction speed | Klipper | Host multi-move paths only (future) |
| Minimum cruise ratio | Klipper short zigzags | Not yet |
| Pressure advance | Klipper extruder | N/A for pure axes |

Precision work should ship the 1.12 defaults (S-curve + Ka + LUT). Raise
current/µsteps only for short open-loop speed tests, then restore.

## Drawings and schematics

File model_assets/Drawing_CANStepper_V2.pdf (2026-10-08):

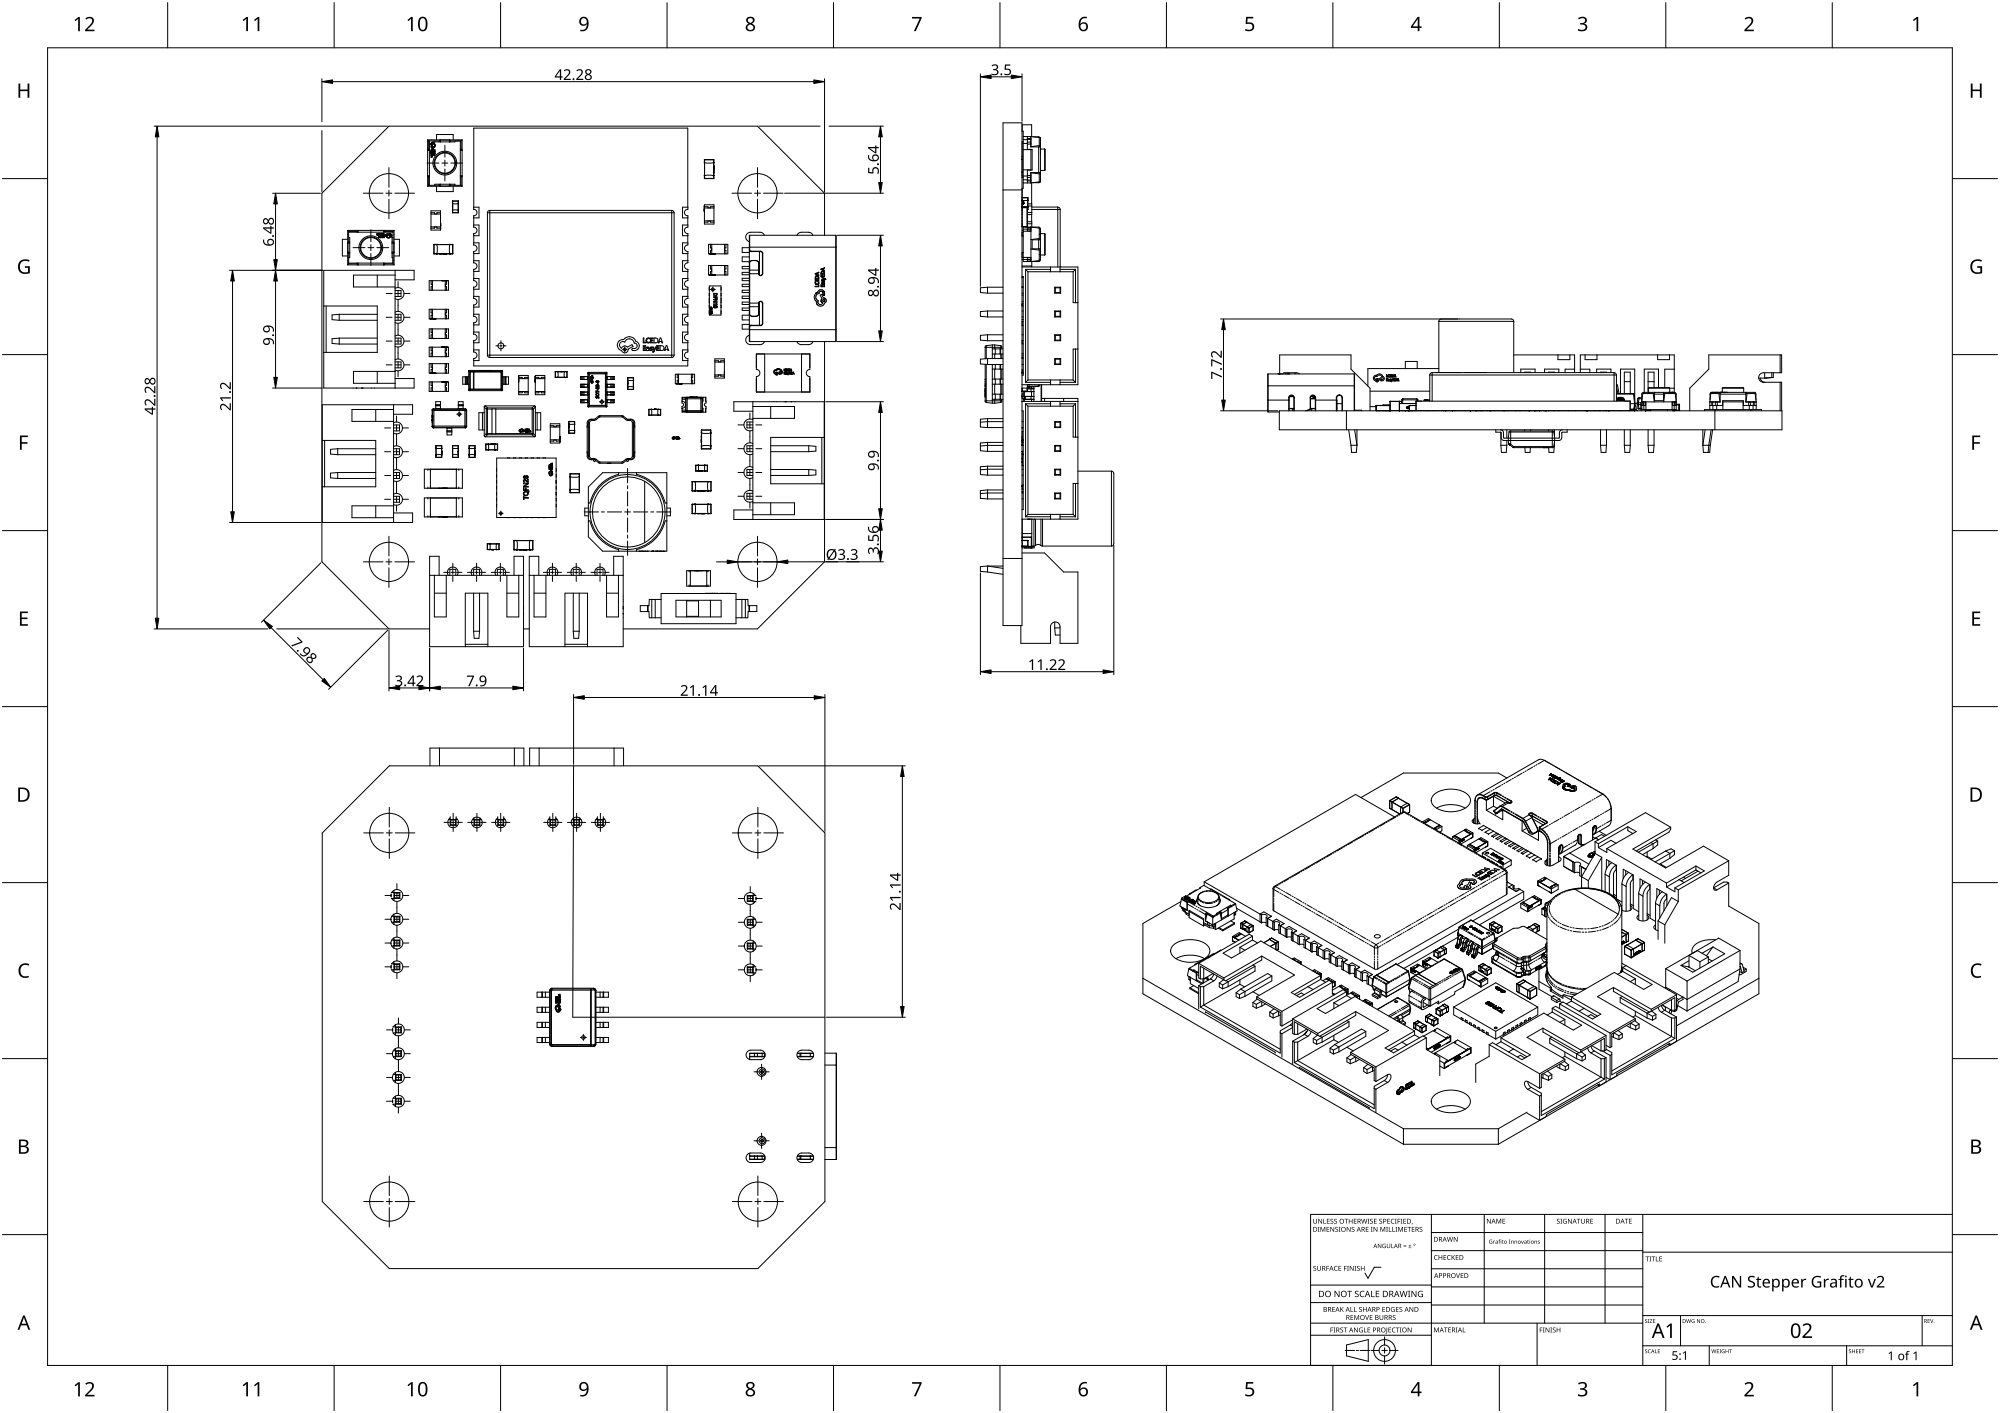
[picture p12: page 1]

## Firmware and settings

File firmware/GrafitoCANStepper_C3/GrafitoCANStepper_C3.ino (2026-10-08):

/*
 * GrafitoCANStepper_C3 — Grafito Innovations CAN stepper node firmware
 *
 * Original firmware for the Grafito CANStepper board:
 *   ESP32-C3 + TMC2209 (UART) + MT6701 magnetic encoder (SSI) + TCAN3413 (CAN).
 *
 * Implements the Grafito CAN Stepper Protocol v1 (GCSP v1).
 * Protocol reference: can_stepper/docs/protocol.md
 *
 * Design notes:
 *  - All tunables live in a single parameter table (SET_PARAM / GET_PARAM),
 *    persisted to NVS with SAVE_CONFIG and loaded at power-on. Motion limits
 *    (max speed, closed-loop speed/accel) are DEFAULTS ONLY — the firmware
 *    never hard-clamps them; change them at runtime and persist as you wish.
 *  - HOME/endstop switch on IO8: configurable enable, polarity and action
 *    (report / stop / stop+zero), plus endstop-based homing (HOME command).
 *  - Homing methods: 0 = zero here, 1 = physical endstop, 2 = StallGuard.
 *  - Closed-loop position (fw ≥1.11): rest-to-rest 7-segment S-curve
 *    (jerk-limited a(t)) generates r(t), v_ff(t), a_ff(t). Command:
 *    v = v_ff + Ka·a_ff + PID(r − encoder). Optional 200-step MT6701 LUT
 *    (fw ≥1.10) linearizes detent INL. FOLLOW uses a braking-law chase.
 *  - Leader/follower: a node can track another node's broadcast POSITION
 *    telemetry (gear ratio, invert, optional encoder correction).
 *  - CAN bus-off self-recovery (a node powered alone must not go mute).
 *  - USB serial <-> CAN bridge so a host can drive the whole bus from any node.
 *
 * Build (Arduino IDE / arduino-cli, esp32 core, board: ESP32C3 Dev Module):
 *  - Tools > USB CDC On Boot: Enabled
 *  - Libraries: FastAccelStepper (gin66), TMC2209 (janelia-arduino)
 *
 * Boot caution — ESP32-C3 strapping pins (datasheet Table 3-3):
 *   IO2 (encoder CS), IO8 (HOME), IO9 (BOOT) sample *only at reset release*.
 *   SPI flash boot wants GPIO8 = 1 (HIGH). After boot, GPIO8 is a normal GPIO.
 *   A CLOSED switch (or optical output) holding IO8 LOW at power-on can force
 *   Joint Download Boot instead of SPI boot — board appears "dead" until released.
 *   Prefer: NO mechanical switch to GND (open at rest = HIGH), or an optical
 *   open-collector that is *not* sinking at power-on.
 *
 * HOME wiring (default in this build: active-high, endstop enabled):
 *   Pressed/active ≈ GPIO8 HIGH; released ≈ LOW (or open if external drive).
 *   ESP32-C3 strapping: keep GPIO8 HIGH at power-on for normal SPI boot —
 *   do not leave a closed active-low switch holding IO8 LOW across reset.
 *   Runtime override still possible via ENDSTOP_* params + SAVE_CONFIG unless
 *   the boot hard-defaults below re-apply them each power-on.
 */

#include <FastAccelStepper.h>
#include <TMC2209.h>
#include <SPI.h>
#include <Preferences.h>
#include "driver/twai.h"
#include <math.h>
#include <stdint.h>
#include <string.h>

// ============================================================================
// Firmware / protocol identity
// ============================================================================
static const uint8_t FW_MAJOR  = 1;
static const uint8_t FW_MINOR  = 12;  // 1.12: measured precision defaults (S-curve+Ka+LUT)
static const uint8_t PROTO_VER = 1;

// ============================================================================
// Board pin map (Grafito CANStepper C3 schematic)
// ============================================================================
static const int PIN_CAN_TX   = 21;  // -> TCAN3413 TXD
static const int PIN_CAN_RX   = 20;  // -> TCAN3413 RXD
static const int PIN_TMC_EN   = 3;   // TMC2209 EN (LOW = driver on)
static const int PIN_STEP     = 10;
static const int PIN_DIR      = 1;
static const int PIN_DIAG     = 0;   // TMC2209 DIAG (StallGuard), via 1k
static const int PIN_TMC_TX   = 7;   // PDN_UART via 1k series resistor
static const int PIN_TMC_RX   = 6;   // PDN_UART direct
static const int PIN_ENC_CLK  = 4;   // MT6701 SSI clock
static const int PIN_ENC_DO   = 5;   // MT6701 SSI data
static const int PIN_ENC_CS   = 2;   // MT6701 chip select (strapping pin)
static const int PIN_HOME     = 8;   // endstop input (strapping pin — see note)

// ============================================================================
// GCSP v1 message IDs.  CAN ID = (node_id << 6) | msg_id.  node 0 = broadcast.
// ============================================================================
enum Cmd : uint8_t {
  CMD_PING          = 0,
  CMD_ESTOP         = 1,
  CMD_STOP          = 2,
  CMD_ENABLE        = 3,
  CMD_MOVE_ABS      = 4,   // f64 degrees
  CMD_MOVE_REL      = 5,   // f64 degrees
  CMD_MOVE_VEL      = 6,   // f32 deg/s signed
  CMD_SET_ZERO      = 7,
  CMD_HOME          = 8,   // u8 method, i8 dir, f32 speed deg/s
  CMD_SET_PARAM     = 9,   // u8 param_id, 4-byte value
  CMD_GET_PARAM     = 10,  // u8 param_id
  CMD_SAVE_CONFIG   = 11,
  CMD_LOAD_DEFAULTS = 12,
  CMD_FOLLOW        = 13,  // u8 en, u8 leader, u8 flags, u8 rsvd, f32 ratio
  CMD_FOLLOW_SYNC   = 14,
  CMD_SET_POSITION  = 15,  // f64 logical angle here; shaft does not move
  CMD_LUT           = 16,  // u8 action: 0 cal, 1 enable, 2 disable, 3 clear
};

enum Tel : uint8_t {
  TEL_STATUS        = 32,  // flags, mode, fault, fw_major, fw_minor, proto, node
  TEL_POSITION      = 33,  // f64 encoder angle deg (drives followers)
  TEL_MOTION        = 34,  // f32 velocity deg/s, f32 position error deg
  TEL_TARGET        = 35,  // f64 target deg (RTR)
  TEL_EVENT         = 36,  // u8 event, u8 detail, f32 data
  TEL_DRIVER        = 37,  // TMC diagnostics (see sendDriver); 8 bytes
  TEL_ENV           = 38,  // f32 mcu temp C, f32 vbus V
  TEL_PARAM         = 39,  // u8 param_id, u8 status, 4-byte value
  TEL_FOLLOW_STATUS = 40,  // u8 en, u8 leader, u8 flags, u8 synced, f32 ratio
  TEL_CAN_HEALTH    = 41,  // u8 state, u8 tx_err, u8 rx_err, u8 recov, u16, u16
  TEL_ENC_COUNTS    = 42,  // i64 multi-turn encoder counts (RTR)
  TEL_PID_STATUS    = 43,  // u8 state, u8 fault, f32 output deg/s
  TEL_LUT_STATUS    = 44,  // u8 valid, u8 enabled, u16 n, f32 peak_inl_deg
};

// TEL_DRIVER layout (little-endian, 8 bytes) — GCSP fw ≥1.4
//   [0..1] u16 stallguard result
//   [2]    flags_a:
//            bit0 uart_ok
//            bit1 otpw   (over-temperature pre-warning)
//            bit2 ot     (over-temperature shutdown)
//            bit3 s2ga   (short to GND A)
//            bit4 s2gb
//            bit5 s2vsa  (low-side short A)
//            bit6 s2vsb
//            bit7 ola    (open load A)
//   [3]    flags_b:
//            bit0 olb
//            bit1 t120 / bit2 t143 / bit3 t150 / bit4 t157 (temp thresholds)
//            bit5 stealth_chop_mode
//            bit6 standstill
//            bit7 reserved
//   [4]    gstat: bit0 reset, bit1 drv_err, bit2 uv_cp
//   [5]    cs_actual (0..31) — actual current scale from DRV_STATUS
//   [6..7] u16 interstep duration (TSTEP-style, low 16 bits of getInterstepDuration)

enum Event : uint8_t {
  EVT_BOOT = 1, EVT_ENDSTOP_HIT = 2, EVT_ENDSTOP_RELEASED = 3, EVT_STALL = 4,
  EVT_HOMING_DONE = 5, EVT_HOMING_FAILED = 6, EVT_MOVE_DONE = 7,
  EVT_ESTOP = 8, EVT_FAULT = 9,
  EVT_LUT_DONE = 10, EVT_LUT_FAILED = 11,
};

enum Mode : uint8_t {
  MODE_IDLE = 0, MODE_POSITION = 1, MODE_VELOCITY = 2,
  MODE_HOMING = 3, MODE_FOLLOW = 4, MODE_LUT = 5,
};

enum Fault : uint8_t {
  FAULT_NONE = 0, FAULT_ENCODER = 1, FAULT_NO_PROGRESS = 2,
  FAULT_HOMING_TIMEOUT = 3,
  FAULT_DRIVER_OT = 4,       // TMC over-temperature shutdown (OT)
  FAULT_DRIVER_SHORT = 5,    // TMC short-to-GND or low-side short
};

enum ParamStatus : uint8_t { PS_OK = 0, PS_UNKNOWN = 1, PS_REJECTED = 2 };

// ============================================================================
// Parameter table.  Each parameter is a 4-byte value (u32 or f32).
// Sanity limits protect hardware addressing/registers only — motion limits
// are user policy: defaults below, fully changeable at runtime, no clamps.
// ============================================================================
enum ParamId : uint8_t {
  P_NODE_ID             = 1,   // u32 1..31
  P_STEPS_PER_REV       = 2,   // u32 full steps per motor revolution
  P_MICROSTEPS          = 3,   // u32 power of two 1..256 (TMC register constraint)
  P_RUN_CURRENT         = 4,   // u32 percent 1..100
  P_HOLD_CURRENT        = 5,   // u32 percent 0..100
  P_STALL_THRESHOLD     = 6,   // u32 SGTHRS 0..255
  P_INVERT_DIR          = 7,   // u32 bool
  P_CLOSED_LOOP         = 8,   // u32 bool
  P_MAX_SPEED           = 9,   // f32 deg/s used for position moves
  P_ACCELERATION        = 10,  // f32 deg/s^2
  P_CL_MAX_SPEED        = 11,  // f32 deg/s closed-loop cruise ceiling (default 720)
  P_CL_MAX_ACCEL        = 12,  // f32 deg/s^2 S-curve amax while closed loop (default 1440)
  P_PID_KP              = 13,  // f32
  P_PID_KI              = 14,  // f32
  P_PID_KD              = 15,  // f32
  P_PID_TOLERANCE       = 16,  // f32 deg
  P_FAST_RATE_HZ        = 17,  // u32 0..500  (POSITION/MOTION/PID_STATUS)
  P_SLOW_RATE_HZ        = 18,  // u32 0..500  (STATUS/DRIVER/ENV/FOLLOW/CAN health)
  P_ENABLE_ON_BOOT      = 19,  // u32 bool
  P_ZERO_ON_BOOT        = 20,  // u32 bool
  P_STANDSTILL_MODE     = 21,  // u32 0 normal,1 freewheel,2 brake,3 strong brake
  P_ENDSTOP_ENABLE      = 22,  // u32 bool
  P_ENDSTOP_ACTIVE_HIGH = 23,  // u32 bool (0 = active low + pull-up, default)
  P_ENDSTOP_ACTION      = 24,  // u32 0 report,1 stop,2 stop+zero
  P_HOMING_CURRENT      = 25,  // u32 percent, 0 = keep run current
  P_HOMING_BACKOFF      = 26,  // f32 deg retreat after trigger
  P_HOMING_TIMEOUT_MS   = 27,  // u32
  P_STEALTHCHOP         = 28,  // u32 bool
  P_LUT_ENABLE          = 29,  // u32 bool — apply 200-step encoder LUT
  P_CL_MAX_JERK         = 30,  // f32 deg/s^3; 0 = auto (amax / 0.05 s)
  P_PID_KA              = 31,  // f32 s — acceleration feedforward (v += Ka·a)
  PARAM_MAX             = 31,
};

union ParamValue { uint32_t u; float f; };

struct ParamDef {
  uint8_t  id;
  bool     isFloat;
  float    def;      // default (cast for u32 params)
  float    minv;     // sanity range (hardware validity, not policy)
  float    maxv;
};

static const ParamDef PARAM_DEFS[] = {
  { P_NODE_ID,             false, 1,       1,      31       },
  { P_STEPS_PER_REV,       false, 200,     1,      100000   },
  { P_MICROSTEPS,          false, 16,      1,      256      },
  // Currents are % of TMC peak (hardware-dependent). Low defaults for multi-node
  // mesh power: host must raise RUN/HOLD for loaded axes and call enable().
  { P_RUN_CURRENT,         false, 20,      1,      100      },  // was 30
  { P_HOLD_CURRENT,        false, 5,       0,      100      },  // was 15 — idle torque
  { P_STALL_THRESHOLD,     false, 10,      0,      255      },
  { P_INVERT_DIR,          false, 0,       0,      1        },
  { P_CLOSED_LOOP,         false, 1,       0,      1        },
  { P_MAX_SPEED,           true,  720.0f,  0.001f, 1e9f     },
  { P_ACCELERATION,        true,  1440.0f, 0.001f, 1e9f     },
  { P_CL_MAX_SPEED,        true,  720.0f,  0.001f, 1e9f     },
  { P_CL_MAX_ACCEL,        true,  1440.0f, 0.001f, 1e9f     },
  // Tracking gains (S-curve v_ff + Ka·a_ff carry the move; PID trims residual).
  // Defaults from PR42HS40-1204AF-02 @ 24 V, fw 1.11 bench (median |err| 0.13°).
  { P_PID_KP,              true,  10.0f,   0.0f,   1e6f     },
  { P_PID_KI,              true,  0.3f,    0.0f,   1e6f     },
  { P_PID_KD,              true,  0.35f,   0.0f,   1e6f     },
  { P_PID_TOLERANCE,       true,  0.35f,   0.001f, 360.0f   },
  { P_FAST_RATE_HZ,        false, 10,      0,      500      },
  { P_SLOW_RATE_HZ,        false, 1,       0,      500      },
  { P_ENABLE_ON_BOOT,      false, 0,       0,      1        },  // was 1 — mesh idle off
  { P_ZERO_ON_BOOT,        false, 0,       0,      1        },
  { P_STANDSTILL_MODE,     false, 1,       0,      3        },  // freewheel when standing
  { P_ENDSTOP_ENABLE,      false, 1,       0,      1        },  // on: stop on HOME
  { P_ENDSTOP_ACTIVE_HIGH, false, 1,       0,      1        },  // pressed = GPIO8 HIGH
  { P_ENDSTOP_ACTION,      false, 1,       0,      2        },  // 1 = stop
  { P_HOMING_CURRENT,      false, 0,       0,      100      },
  { P_HOMING_BACKOFF,      true,  2.0f,    0.0f,   36000.0f },
  { P_HOMING_TIMEOUT_MS,   false, 30000,   100,    600000   },
  { P_STEALTHCHOP,         false, 1,       0,      1        },
  { P_LUT_ENABLE,          false, 0,       0,      1        },
  { P_CL_MAX_JERK,         true,  0.0f,    0.0f,   1e9f     },
  { P_PID_KA,              true,  0.04f,   0.0f,   1.0f     },
};
static const size_t PARAM_COUNT = sizeof(PARAM_DEFS) / sizeof(PARAM_DEFS[0]);

static ParamValue params[PARAM_MAX + 1];   // indexed by ParamId

static const ParamDef *paramDef(uint8_t id) {
  for (size_t i = 0; i < PARAM_COUNT; i++)
    if (PARAM_DEFS[i].id == id) return &PARAM_DEFS[i];
  return nullptr;
}
static inline uint32_t pu(uint8_t id) { return params[id].u; }
static inline float    pf(uint8_t id) { return params[id].f; }

// ============================================================================
// Globals
// ============================================================================
Preferences prefs;
TMC2209 tmc;
FastAccelStepperEngine stepperEngine;
FastAccelStepper *stepper = nullptr;
static SPIClass encSpi(FSPI);

static uint8_t  nodeId = 1;
static uint8_t  mode = MODE_IDLE;
static uint8_t  fault = FAULT_NONE;
static bool     driverEnabled = false;
static bool     estopLatched = false;
static bool     homed = false;

// encoder (MT6701, 14-bit angle -> 16384 counts/rev, multi-turn accumulated)
static const int32_t ENC_CPR = 16384;
static int64_t  encCounts = 0;         // multi-turn counts minus zero offset
static int64_t  encZeroOffset = 0;
static bool     encFrameOk = true;
static uint32_t encBadFrames = 0;
static bool     encHasGoodFrame = false;
static uint32_t encLastGoodUs = 0;
// A single SSI CRC error must not abort a move. Hold the last valid sample and
// fault only if feedback is continuously unavailable for this long.
static const uint32_t ENC_LOSS_TIMEOUT_US = 25000;  // five 200 Hz PID periods

// 200-step encoder LUT (one entry per 1.8° motor detent)
static const uint16_t LUT_N = 200;
static const uint32_t LUT_MAGIC = 0x314C4547;  // 'GEL1'
static const uint32_t LUT_SETTLE_MS = 60;
static bool     lutValid = false;
static bool     lutEnabled = false;
static uint16_t lutE[200];
static int32_t  lutU[201];
static float    lutPeakInlDeg = 0.0f;
static uint8_t  lutPhase = 0;       // 0 idle, 1 running
static uint8_t  lutPass = 0;        // 0 forward, 1 reverse
static uint16_t lutIndex = 0;
static bool     lutNeedCapture = false;
static uint32_t lutWaitMs = 0;
static uint16_t lutFwd[200];
static uint16_t lutRev[200];
static uint32_t lutSavedClosed = 0;
static uint32_t lutSavedStandstill = 0;
static uint32_t lutSavedHold = 0;
static uint32_t lutSavedEndstop = 0;

// motion bookkeeping
static double   targetDeg = 0.0;       // active position/homing/follow target
static float    velTargetDegS = 0.0f;  // active velocity command
static int      cmdDirSign = 0;        // sign of last commanded motion
static bool     moveDonePending = false;

// Closed-loop: trapezoidal trajectory + velocity feedforward + tracking PID
static const uint32_t PID_PERIOD_US = 5000;     // 200 Hz
static const uint32_t PID_SETTLE_MS = 80;
static const uint32_t PID_STALL_TIMEOUT_MS = 3000;
static const float    PID_SETTLE_VEL_FRAC = 0.06f;
static const float    PID_SETTLE_VEL_MIN  = 12.0f;
static uint8_t  pidState = 0;          // 0 idle, 1 running, 2 settled, 3 fault
static float    pidOutDegS = 0.0f;
static float    pidErrDeg = 0.0f;      // target − measured (telemetry)
static float    pidIntegral = 0.0f;
static float    pidVelFilt = 0.0f;
static double   pidPrevDeg = 0.0;
static uint32_t pidPrevUs = 0;
static uint32_t pidSettleStartMs = 0;
static float    pidBestErr = 1e30f;
static uint32_t pidProgressMs = 0;
static bool     pidStopping = false;   // waiting for stop before reversing

// Rest-to-rest 7-segment S-curve (finite jerk) + velocity/accel feedforward.
// POSITION moves plan once at beginPositionMove; FOLLOW uses online braking.
static bool   trajActive = false;
static bool   trajDone = true;
static double trajS0 = 0.0;
static double trajS1 = 0.0;
static float  trajSign = 1.0f;
static float  trajDist = 0.0f;
static float  trajVpeak = 0.0f;
static float  trajA = 1.0f;
static float  trajJ = 1.0f;
static float  trajTj = 0.0f;           // jerk-in / jerk-out duration
static float  trajTc = 0.0f;           // constant-accel duration
static float  trajTv = 0.0f;           // cruise duration
static float  trajTtot = 0.0f;
static float  trajT = 0.0f;
static double trajRef = 0.0;           // position reference r(t)
static float  trajVff = 0.0f;          // velocity feedforward v_ff(t)
static float  trajAff = 0.0f;          // acceleration feedforward a_ff(t)

// endstop (GPIO8 / PIN_HOME — strapping pin, see file header)
static bool     endstopActive = false;   // logical active (after polarity)
static bool     endstopRawHigh = true;   // last digitalRead (true = pin HIGH)
static uint32_t endstopChangeMs = 0;
static const uint32_t ENDSTOP_DEBOUNCE_MS = 5;

// homing
static uint8_t  homingMethod = 0;
static int8_t   homingDir = 1;
static float    homingSpeed = 0.0f;
static uint8_t  homingPhase = 0;       // 0 off, 1 seeking, 2 backing off
static uint32_t homingStartMs = 0;
static uint32_t savedRunCurrent = 0;

// StallGuard
static volatile bool stallFlag = false;

// follower
static bool    followEnabled = false;
static uint8_t followLeader = 0;
static bool    followInvert = false;
static bool    followEncCorrected = true;
static float   followRatio = 1.0f;
static bool    followSynced = false;
static double  followLeaderRefDeg = 0.0;
static double  followAcceptedDeg = 0.0;
static double  followLocalRefDeg = 0.0;
static int32_t followLocalRefSteps = 0;
static int32_t followLastTarget = 0;
static bool    followTargetValid = false;
static const double FOLLOW_DEADBAND_DEG = 0.15;

// CAN health
static uint8_t  canRecoveries = 0;
static bool     canRestartPending = false;
static uint32_t canHealthMs = 0;

// telemetry scheduling
static uint32_t fastTelMs = 0;
static uint32_t slowTelMs = 0;

// serial bridge line buffer
static char   lineBuf[80];
static size_t lineLen = 0;

// ============================================================================
// Small helpers
// ============================================================================
static inline double stepsPerDeg() {
  return (double)pu(P_STEPS_PER_REV) * (double)pu(P_MICROSTEPS) / 360.0;
}
static inline double countsToDeg(int64_t c) { return (double)c * 360.0 / ENC_CPR; }
static inline double encoderDeg() { return countsToDeg(encCounts); }

static void lutFail(uint8_t reason);
static void lutBegin();
static void lutService();
static void lutClear();
static void lutLoadNvs();
static void lutSaveNvs();

static void IRAM_ATTR onDiagRise() { stallFlag = true; }

// ============================================================================
// MT6701 encoder over SSI (24-bit frame: 14-bit angle, 4-bit status, 6-bit CRC)
// ============================================================================
static uint8_t crc6_itu(uint32_t data18) {
  // CRC-6/ITU, poly x^6 + x + 1, over the 18 data bits, MSB first.
  uint8_t crc = 0;
  for (int i = 17; i >= 0; i--) {
    uint8_t bit = (data18 >> i) & 1;
    uint8_t msb = (crc >> 5) & 1;
    crc = (uint8_t)((crc << 1) & 0x3F);
    if (bit ^ msb) crc ^= 0x03;
  }
  return crc;
}

static int32_t lutUnwrapDelta(int32_t a, int32_t b) {
  int32_t d = (b - a) % ENC_CPR;
  if (d < 0) d += ENC_CPR;
  if (d > ENC_CPR / 2) d -= ENC_CPR;
  return d;
}

static void lutRebuild() {
  if (!lutValid) return;
  lutU[0] = (int32_t)lutE[0];
  for (uint16_t k = 1; k < LUT_N; k++)
    lutU[k] = lutU[k - 1] + lutUnwrapDelta(lutE[k - 1], lutE[k]);
  lutU[LUT_N] = lutU[0] + ENC_CPR;
  float peak = 0.0f;
  for (uint16_t k = 0; k < LUT_N; k++) {
    float meas = (float)(lutU[k] - lutU[0]);
    float expect = (float)k * ((float)ENC_CPR / (float)LUT_N);
    float err = fabsf(meas - expect) * 360.0f / (float)ENC_CPR;
    if (err > peak) peak = err;
  }
  lutPeakInlDeg = peak;
}

static uint16_t lutApply(uint16_t raw) {
  if (!lutValid || !lutEnabled) return raw;
  int32_t q = lutU[0] + lutUnwrapDelta(lutE[0], (int32_t)raw);
  while (q < lutU[0]) q += ENC_CPR;
  while (q >= lutU[0] + ENC_CPR) q -= ENC_CPR;
  uint16_t lo = 0, hi = LUT_N;
  while ((uint16_t)(lo + 1) < hi) {
    uint16_t mid = (uint16_t)((lo + hi) >> 1);
    if (lutU[mid] <= q) lo = mid;
    else hi = mid;
  }
  int32_t u0 = lutU[lo];
  int32_t u1 = lutU[lo + 1];
  float frac = (u1 == u0) ? 0.0f : (float)(q - u0) / (float)(u1 - u0);
  float cal = ((float)lo + frac) * ((float)ENC_CPR / (float)LUT_N);
  int32_t ic = (int32_t)lroundf(cal) % ENC_CPR;
  if (ic < 0) ic += ENC_CPR;
  return (uint16_t)ic;
}
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
void loop() {
  canHealthService();
  tmcDriverService();

  // Drain the CAN RX queue.
  twai_message_t rx;
  while (twai_receive(&rx, 0) == ESP_OK) {
    if (rx.extd) continue;
    if (!rx.rtr) serialPrintFrame(rx.identifier, false, rx.data, rx.data_length_code);
    dispatchFrame(rx.identifier, rx.rtr, rx.data, rx.data_length_code);
  }

  serialService();
  endstopService();
  homingService();
  lutService();
  velocityService();

  if (stallFlag && mode != MODE_HOMING) {
    stallFlag = false;
    sendEvent(EVT_STALL, 0, (float)encoderDeg());
  }

  pidService();
  moveDoneService();
  telemetryService();

  delay(1);
}

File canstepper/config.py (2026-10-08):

"""Declarative machine configuration (TOML or dict).

Example ``machine.toml``::

    [bus]
    transport = "serial"
    port = "/dev/ttyACM0"

    [node.z_left]
    id = 2
    run_current = 40
    microsteps = 16
    closed_loop = 1

    [node.z_right]
    id = 3
    run_current = 40

    [axis.z]
    type = "dual_motor"
    primary = "z_left"
    secondary = "z_right"
    invert_secondary = true
    rotation_distance = 8.0
    max_speed = 20.0

    [axis.z.homing]
    method = "stallguard"
    direction = -1
    speed = 5.0

Any key in a ``[node.*]`` table other than ``id`` must be a firmware
parameter name from :data:`canstepper.protocol.PARAMS` and is applied (and
verified) on load.
"""

from __future__ import annotations

from pathlib import Path
from typing import Any, Dict, Optional, Union

from .axis import Axis
from .bus import CANStepperBus
from .exceptions import ConfigError
from .kinematics import CoreXY, DualMotorAxis, IndependentDualAxis
from .node import StepperNode
from .protocol import PARAMS_BY_NAME, resolve_param

_AXIS_KEYS = {
    "type", "node", "primary", "secondary", "motor_a", "motor_b",
    "node_a", "node_b",
    "rotation_distance", "gear_ratio", "min_pos", "max_pos", "max_speed",
    "require_homing", "invert_secondary", "invert_a", "invert_b",
    "invert_primary", "ratio", "encoder_corrected",
    "tol_mm", "settle_s", "gate_timeout_s",
    "homing",
}


def _load_toml(path: Union[str, Path]) -> Dict[str, Any]:
    try:
        import tomllib  # Python 3.11+
    except ImportError:
        try:
            import tomli as tomllib  # type: ignore[no-redef]
        except ImportError as exc:
            raise ConfigError(
                "reading TOML on Python < 3.11 requires the 'tomli' package "
                "(pip install tomli), or pass a dict instead of a path"
            ) from exc
    with open(path, "rb") as fh:
        return tomllib.load(fh)


class Machine:
    """A whole machine: bus + named nodes + named axes, built from config."""

    def __init__(self, bus: CANStepperBus, owns_bus: bool = False):
        self.bus = bus
        self._owns_bus = owns_bus
        self.nodes: Dict[str, StepperNode] = {}
        self.axes: Dict[str, Union[Axis, DualMotorAxis, CoreXY, IndependentDualAxis]] = {}
        self.homing: Dict[str, Dict[str, Any]] = {}

    # -- construction ---------------------------------------------------------

    @classmethod
    def from_config(
        cls,
        source: Union[str, Path, Dict[str, Any]],
        bus: Optional[CANStepperBus] = None,
        apply: bool = True,
    ) -> "Machine":
        """Build a Machine from a TOML file path or an equivalent dict.

        With ``apply=True`` every node parameter in the config is written to
        (and acknowledged by) the hardware. Values are volatile until you
        call :meth:`save_all`.
        """
        cfg = _load_toml(source) if not isinstance(source, dict) else source

        owns_bus = bus is None
        if bus is None:
            bus_cfg = cfg.get("bus", {})
            transport = bus_cfg.get("transport", "serial")
            if transport != "serial":
                raise ConfigError(f"unsupported transport {transport!r}")
            port = bus_cfg.get("port")
            if not port:
                raise ConfigError("[bus] needs a 'port' for the serial transport")
            bus = CANStepperBus.serial(port, baudrate=bus_cfg.get("baudrate", 115200))

        machine = cls(bus, owns_bus=owns_bus)
        try:
            machine._build_nodes(cfg.get("node", {}), apply=apply)
            machine._build_axes(cfg.get("axis", {}), apply=apply)
        except Exception:
            if owns_bus:
                bus.close()
            raise
        return machine

    def _build_nodes(self, node_cfg: Dict[str, Any], apply: bool) -> None:
        for name, table in node_cfg.items():
            if "id" not in table:
                raise ConfigError(f"[node.{name}] is missing 'id'")
            node = self.bus.node(int(table["id"]))
            self.nodes[name] = node
            for key, value in table.items():
                if key == "id":
                    continue
                if key.lower() not in PARAMS_BY_NAME:
                    raise ConfigError(
                        f"[node.{name}] unknown parameter {key!r} "
                        f"(see canstepper.protocol.PARAMS)"
                    )
                if apply:
                    node.set_param(key, value)

    def _node_ref(self, axis_name: str, table: Dict[str, Any], key: str) -> StepperNode:
        ref = table.get(key)
        if ref is None:
            raise ConfigError(f"[axis.{axis_name}] is missing {key!r}")
        if ref not in self.nodes:
            raise ConfigError(
                f"[axis.{axis_name}] references unknown node {ref!r}"
            )
        return self.nodes[ref]
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

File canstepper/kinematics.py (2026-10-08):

"""Coordinated multi-motor motion: MotionGroup, DualMotorAxis,
IndependentDualAxis, Cartesian, CoreXY.

Coordination model (v1): point-to-point *time-synchronized* moves. The host
computes one common move duration and scales each motor's cruise speed and
acceleration so all motors start together and finish together. Start skew is
one CAN frame per motor (~0.15 ms at 1 Mbps) plus host scheduling; this is
excellent for gantries, pick-and-place and feeders, but it is not a
continuous-path (contouring) controller.

Kinematics (Klipper-inspired naming):

* :class:`Cartesian` — independent X/Y/(Z) steppers; motor travel = workspace
  travel on each axis (``kinematics: cartesian`` style).
* :class:`CoreXY` — coupled belts ``A=X+Y``, ``B=X-Y``.
* :class:`DualMotorAxis` — two motors on one linear axis (e.g. dual-Z gantry)
  via firmware leader/follower (no host in the coupling loop).
* :class:`IndependentDualAxis` — two motors each close their own loop (or
  open-loop steps); host **encoder-gates** the next pass until *both*
  encoders are within tolerance of the commanded mm target. Proven path for
  dual SFU1204 ball-screw frames.
"""

from __future__ import annotations

import math
import time
from typing import Callable, Dict, List, Optional, Sequence, Tuple, Union

from .axis import Axis
from .exceptions import EncoderGateTimeout, NodeFault, RequestTimeout
from .node import StepperNode
from .protocol import Event, Param

# StallGuardEstop is typed as object in method signatures to avoid a circular
# import; runtime accepts canstepper.stall_protect.StallGuardEstop.


# ---------------------------------------------------------------------------
# Trapezoidal profile math
#
# Mirrors the firmware ≥1.2 closed-loop planner (rest-to-rest trap / triangle)
# and the host MotionGroup time-sync planner. Velocity diagram::
#
#     v
#     ^
#     |    /--------\        trapezoid (reaches cruise)
#     |   /          \
#     |  /            \
#     +------------------> t
#       accel cruise decel
#
#     v
#     ^
#     |    /\                triangle (short move)
#     |   /  \
#     +----------> t
# ---------------------------------------------------------------------------

def trapezoid_time(distance: float, speed: float, accel: float) -> float:
    """Duration of a trapezoidal (or triangular) move."""
    d = abs(distance)
    if d == 0.0 or speed <= 0.0 or accel <= 0.0:
        return 0.0
    if d >= speed * speed / accel:          # reaches cruise speed
        return d / speed + speed / accel
    return 2.0 * math.sqrt(d / accel)       # triangular profile


def plan_trapezoid(
    distance: float, speed: float, accel: float
) -> Tuple[float, float, float, float, float]:
    """Plan a rest-to-rest trap/triangle.

    Returns ``(v_peak, t_acc, t_cruise, t_dec, t_total)``.
    Matches firmware ``trajPlan()`` (fw ≥1.2).
    """
    d = abs(distance)
    if d <= 0.0 or speed <= 0.0 or accel <= 0.0:
        return 0.0, 0.0, 0.0, 0.0, 0.0
    d_acc_full = (speed * speed) / (2.0 * accel)
    if 2.0 * d_acc_full >= d:
        v_peak = math.sqrt(accel * d)
        t_acc = v_peak / accel
        return v_peak, t_acc, 0.0, t_acc, 2.0 * t_acc
    t_acc = speed / accel
    t_cruise = (d - 2.0 * d_acc_full) / speed
    return speed, t_acc, t_cruise, t_acc, 2.0 * t_acc + t_cruise


def eval_trapezoid(
    distance: float,
    speed: float,
    accel: float,
    t: float,
) -> Tuple[float, float]:
    """Evaluate position along the move and feedforward velocity at time ``t``.

    ``distance`` is signed. Returns ``(s_along_signed, v_ff_signed)`` where
    ``s`` runs from 0 to ``distance``. Used by tests and host-side preview;
    firmware evaluates the same equations in ``trajAdvance()``.
    """
    sign = 1.0 if distance >= 0.0 else -1.0
    d = abs(distance)
    v_peak, t_acc, t_cruise, t_dec, t_tot = plan_trapezoid(d, speed, accel)
    if d <= 0.0 or t_tot <= 0.0:
        return 0.0, 0.0
    if t <= 0.0:
        return 0.0, 0.0
    if t >= t_tot:
        return distance, 0.0

    d_acc = 0.5 * accel * t_acc * t_acc
    if t <= t_acc:
        v = accel * t
        s = 0.5 * accel * t * t
    elif t <= t_acc + t_cruise:
        tc = t - t_acc
        v = v_peak
        s = d_acc + v_peak * tc
    else:
        td = t - t_acc - t_cruise
        v = max(0.0, v_peak - accel * td)
        s = d_acc + v_peak * t_cruise + v_peak * td - 0.5 * accel * td * td
    s = min(d, max(0.0, s))
    return sign * s, sign * v


def profile_for_time(
    distance: float, duration: float, accel: float
) -> Tuple[float, float]:
    """Pick ``(speed, accel)`` that covers ``distance`` in ``duration``.

    Keeps the given acceleration when possible (trapezoid); raises it only
    when the move is too short to reach any cruise speed in time.
    """
    d = abs(distance)
    if d == 0.0 or duration <= 0.0:
        return 0.0, accel
    disc = accel * accel * duration * duration - 4.0 * accel * d
    if disc >= 0.0:
        speed = (accel * duration - math.sqrt(disc)) / 2.0
        if speed > 0.0:
            return speed, accel
    # Triangular fallback: v_peak = 2d/T with a = 4d/T².
    return 2.0 * d / duration, 4.0 * d / (duration * duration)


# ---------------------------------------------------------------------------
# MotionGroup
# ---------------------------------------------------------------------------
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

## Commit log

2026-10-08 Publish the public grafito-canstepper library, firmware, and CAD assets.
    Keep only the host package, production firmware, drawings, and product links. Drop internal bench notes, machine-specific scripts, and bring-up leftovers.
    [CASING_MOUNT.step, Heat_Spreader.step, TMC2209 UART Stepper Driver - Heat_Sink.step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]
2026-10-08 Replace V1 CAD assets with the shop V2 models, drawing, and brochure.
    Keep the public pack aligned with the grafito.in product files: V2 STEP, assembly, pinout, drawing, and brochure.
    [CASING_MOUNT.step]
2026-10-08 Add product photo, labeled pinout, and multi-axis CAN diagram.
    Use CANStepper.png as the README hero image, replace the pinout with the annotated connector drawing, and include the daisy-chain architecture screenshot.
2026-10-08 Add the V1 assembly video plus magnet and connector notes.
    Document that V1 mixed three connector types while V2 uses JST 2.0, and that the MT6701 needs a diametrical magnet with radial polarity.
2026-10-08 Link the Board Test Station for post-connect checks.
    Add the dashboard screenshot and point new boards at https://docs.grafito.in/dashboard after USB and Vin are connected.
2026-10-08 Show the test-station screenshot and V1 video as in-page README previews.
    GitHub Markdown cannot embed the live dashboard or play a local MP4 inline, so the screenshot and a video poster frame render in the README and link through.
2026-10-08 Publish GCSP 1.12 and CANopen 2.1 with a working PLC EDS/DCF pack.
    The previous 2.0 EDS/DCF did not match firmware 2.1 identity or node-2 COB-IDs; FileRevision 2 ships the out-of-box Node2.dcf (0x200C=0).
    [object_dictionary.csv]
2026-10-08 Add a step-by-step firmware flashing guide for GCSP 1.12 and CANopen 2.1.
    Covers Arduino IDE and arduino-cli, Vin/USB-C, board settings, node-2 factory ID, boot banners, and upload failures.
2026-10-08 Document PLC gain tuning for CANopen 2.1 (Kp/Ki/Kd/Ka SDO objects).
    TwinCAT/Codesys must write REAL32 at 0x200F/0x2010/0x2011/0x201A; cruise is 0x6081, not PID.
